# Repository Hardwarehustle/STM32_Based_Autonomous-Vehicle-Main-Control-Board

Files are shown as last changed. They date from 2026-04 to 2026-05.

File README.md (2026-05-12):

# Autonomous Vehicle — Main Control Board (OW_Main_PCB)

---

## Project Overview

This is the **main control board (MCB)** for an autonomous wheeled vehicle, designed to act as the central hub that interfaces the **STM32 Nucleo F446RE** with all vehicle subsystems — motor PWM outputs, relay-controlled actuators, RS-485 temperature sensing, W5500 Ethernet connectivity, and an RGB error-status LED. The board is designed in **KiCad EDA 9.0.7** on a rectangular PCB with four corner mounting holes for secure chassis mounting.

The MCB features:
- **STM32 Nucleo F446RE** piggyback mount on dual female header rows
- **W5500 Ethernet controller** for remote telemetry and control over TCP/IP
- **MAX485 RS-485 transceiver** for robust long-cable sensor/motor communication
- **2× OMRON G5LE-1 relays** for 12V actuator switching
- **4× PWM output ports** (Molex 4-pin) for motor speed control
- **2× Digital I/O ports** for external peripherals
- **RGB error indicator LED** with PWM dimming
- **Dual XT30 power inputs** (12V) with AMS1117-3.3 onboard LDO

---

## Project Visuals

### Schematic
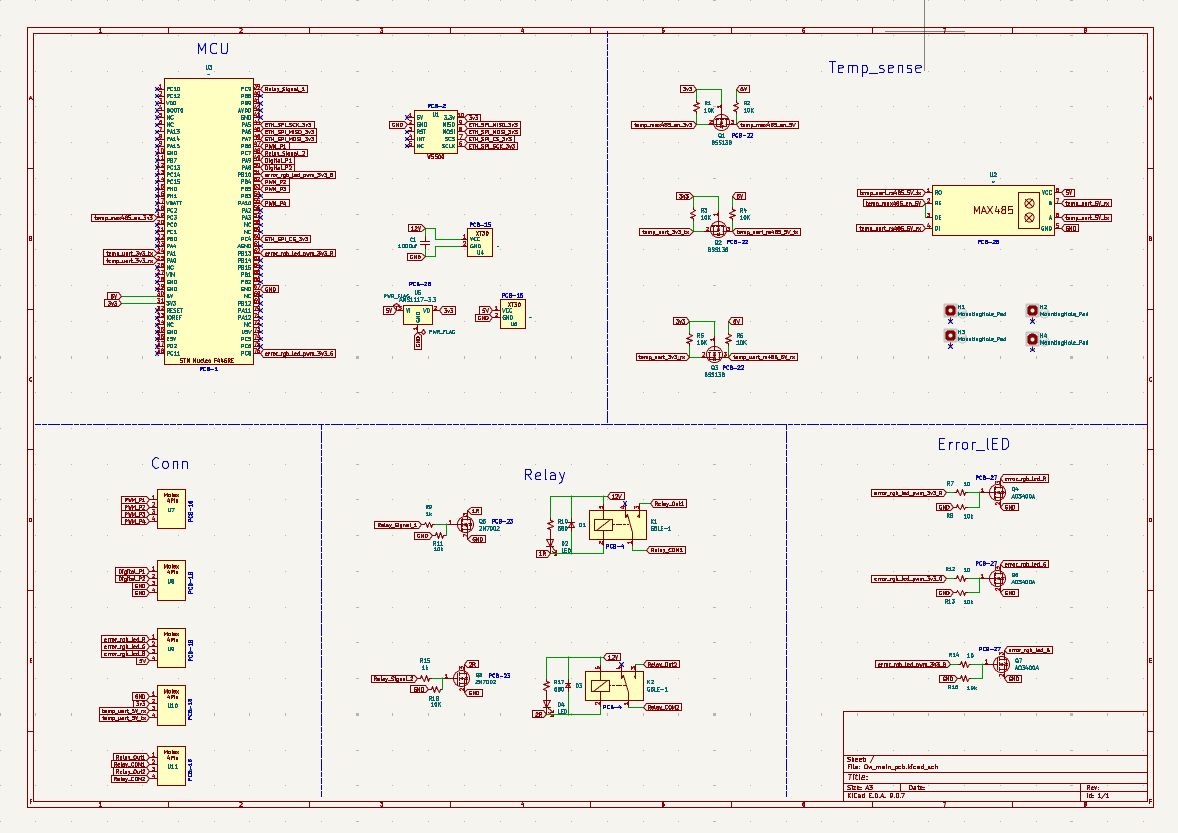
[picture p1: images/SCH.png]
Schematic


### PCB Layout
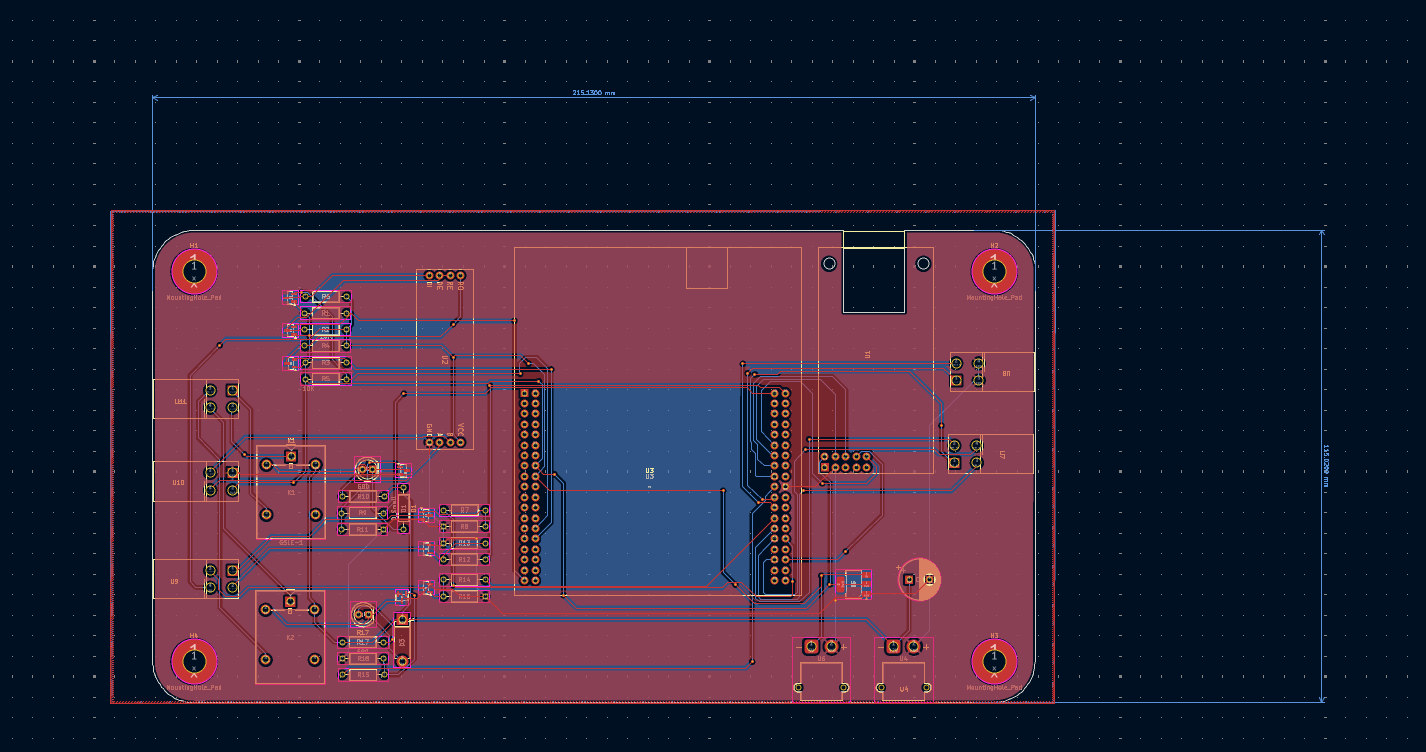
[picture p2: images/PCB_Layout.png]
PCB Layout


### 3D Board Top View
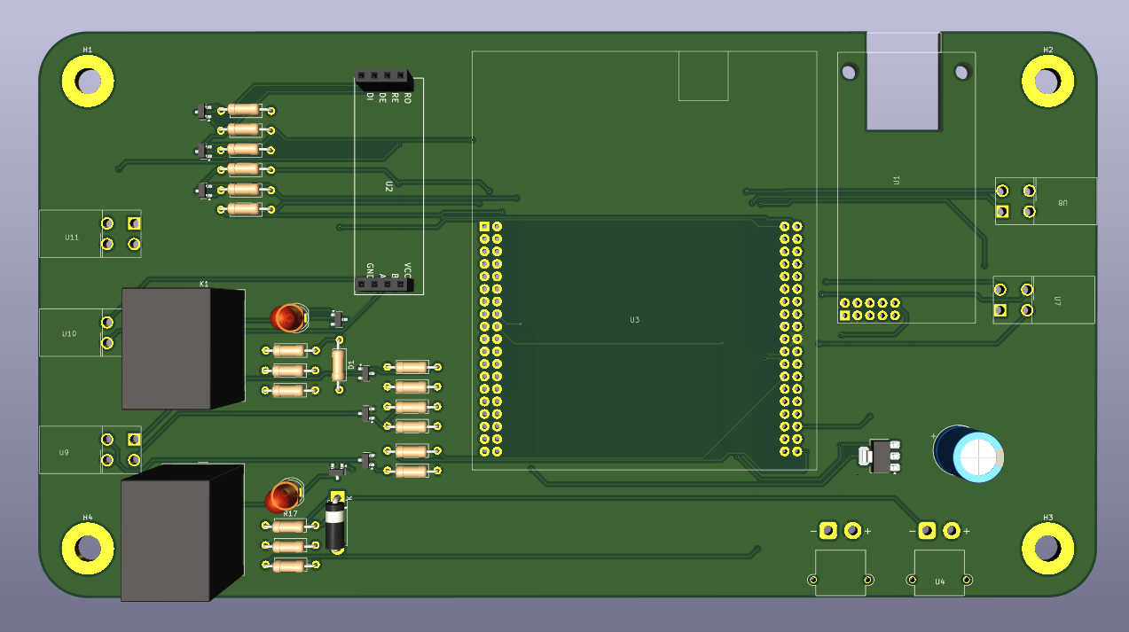
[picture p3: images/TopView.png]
3D Top View


### 3D Board Bottom View
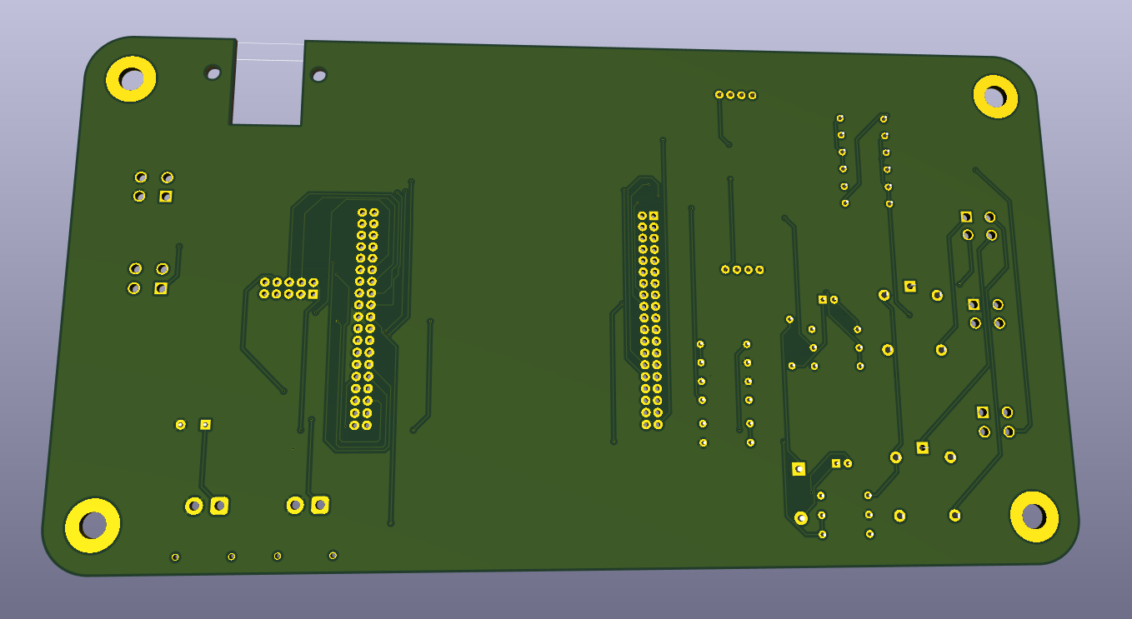
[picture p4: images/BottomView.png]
3D Bottom View


---

## System Architecture

```
12V Power (XT30 ×2)
      │
      ├──► Relay K1, K2 (12V switched outputs — G5LE-1)
      │
      └──► AMS1117-3.3 ──► 3.3V rail
              │
              ▼
      STM Nucleo F446RE (U3)  ◄──── USB/ST-LINK (onboard)
              │
   ┌──────────┼──────────────────────────────────┐
   ▼          ▼            ▼                    ▼
W5500       MAX485      4× PWM Ports      2× Relay Drivers
Ethernet    RS-485      (Motor Control)   (BSS138 / AO3400A)
(SPI 3.3V)  UART Bridge  PWM_P1–P4        K1, K2
   │                         │
   ▼                    Molex 4-pin
TCP/IP                   Connectors
Remote Ctrl              (U7–U11)
                              │
                    Temperature Sensor (RS-485 Bus)
                              │
                         Digital_P1, Digital_P2
                              │
                    RGB Error LED (R, G, B + PWM)
```

---

## Component BOM

### Core ICs & Modules

| Ref | Component | Part | Function |
|:---:|:---|:---|:---|
| U3 | MCU Board | STM Nucleo F446RE | Main controller (STM32F446RET6, 180 MHz) |
| U1 | Ethernet Controller | W5500 | SPI hardwired TCP/IP Ethernet |
| U2 | RS-485 Transceiver | MAX485 (DIP-8) | UART ↔ RS-485 bridge |
| K1, K2 | Relay | OMRON G5LE-1 | 10A SPDT 12V relay (×2) |
| U5 | LDO Regulator | AMS1117-3.3 | 5V → 3.3V supply |
| U6, U4 | Power Connector | XT30 | 12V input (×2) |

### MOSFETs

| Ref | Part | Type | Function |
|:---:|:---|:---|:---|
| Q1, Q2, Q3 | BSS138 | N-ch logic-level FET | Relay coil driving / signal switching |
| Q4, Q6, Q7 | AO3400A | N-ch 5.7A / 30V FET | High-current relay / actuator drive |
| Q5, Q8 | 2N7002 | N-ch logic-level FET | Level shifting / enable control |

### Passives & Indicators

| Ref | Value | Function |
|:---:|:---:|:---|
| R1–R6, R8, R11, R13, R16, R18 | 10 kΩ | Pull-up / pull-down resistors |
| R7, R12, R14 | 10 Ω | Current limiting / damping |
| R9, R15 | 1 kΩ | Gate / base resistors |
| R10, R17 | 680 Ω | LED current limiting |
| C1 | 1000 µF | Bulk supply decoupling |
| D2 | LED (Red) | Error RGB — Red channel |
| D4 | LED (Green) | Error RGB — Green channel |
| D3 | LED (Blue) | Error RGB — Blue channel |
| H1–H4 | MountingHole_Pad | PCB corner mounting holes |

### Peripheral Connectors

| Ref | Type | Signals | Function |
|:---:|:---:|:---|:---|
| U7 | Molex 4-pin | PWM_P1 | PWM Motor Port 1 |
| U8 | Molex 4-pin | PWM_P2 | PWM Motor Port 2 |
| U9 | Molex 4-pin | PWM_P3 | PWM Motor Port 3 |
| U10 | Molex 4-pin | PWM_P4 | PWM Motor Port 4 |
| U11 | Molex 4-pin | Digital_P1/P2 | Digital I/O Ports |

---

## Signal Net Map — STM32 Nucleo F446RE

| Net Name | Nucleo Pin | Function |
|:---|:---:|:---|
| ETH_SPI_MOSI_3v3 | PA7 | W5500 SPI MOSI |
| ETH_SPI_MISO_3v3 | PA6 | W5500 SPI MISO |
| ETH_SPI_SCK_3v3 | PA5 | W5500 SPI Clock |
| ETH_SPI_CS_3v3 | PA4 | W5500 SPI Chip Select |
| temp_uart_rs485_5V_tx | UART TX | MAX485 DI (RS-485 TX) |
| temp_uart_rs485_5V_rx | UART RX | MAX485 RO (RS-485 RX) |
| temp_max485_en_3v3 | GPIO | MAX485 RE/DE enable |
| PWM_P1 – PWM_P4 | TIM PWM pins | 4-channel motor speed control |
| Relay_Signal_1 | GPIO | Relay K1 coil trigger |
| Relay_Signal_2 | GPIO | Relay K2 coil trigger |
| error_rgb_led_pwm_3v3_R | TIM PWM | RGB LED Red (PWM) |
| error_rgb_led_pwm_3v3_G | TIM PWM | RGB LED Green (PWM) |
| error_rgb_led_pwm_3v3_B | TIM PWM | RGB LED Blue (PWM) |
| Digital_P1, Digital_P2 | GPIO | External digital peripherals |

---

## Subsystem Details

### Ethernet — W5500
The **W5500** is a hardwired TCP/IP Ethernet controller that offloads the full network stack (TCP, UDP, IPv4, ARP, ICMP) from the STM32. [web:79] It communicates via **SPI at up to 80 MHz** and supports **8 simultaneous sockets** with 32KB internal buffer. [web:81] This enables:
- Remote **telemetry streaming** (speed, sensor data, state)
- Remote **command injection** over TCP/UDP from a control PC or server
- **OTA firmware update** capability via Ethernet

### RS-485 — MAX485
The **MAX485** is a half-duplex RS-485/RS-422 transceiver driven by the STM32 UART. [file:71] It provides:
- **Up to 2.5 Mbps** data rate
- **±7V common-mode range** — robust against ground shifts in vehicle environments
- Communication with **temperature sensors** or **motor controllers** on a daisy-chain RS-485 bus
- RE/DE pin controlled by MCU GPIO (`temp_max485_en`) for TX/RX direction switching

### Relay Control — G5LE-1 (K1, K2)
Two **OMRON G5LE-1** relays switch 12V loads (actuators, lights, emergency stop) with a rated switching capacity of 10A at 250VAC / 30VDC. [file:71] Each relay is driven by an **AO3400A N-channel MOSFET** (Q4/Q6) with:
- 10kΩ gate pull-down for default OFF state
- BSS138 logic-level gate driver
- Flyback diode protection on coil

### PWM Motor Control
Four **Molex 4-pin ports (U7–U11)** expose PWM signals generated by the STM32's hardware timers. [file:71] Each port carries:
- PWM signal (motor speed reference)
- 5V / 12V power
- GND
- Optional digital I/O

### RGB Error LED
An **RGB LED (D2/D3/D4)** provides visual system status: [file:71]

| Color | State |
|:---:|:---|
|  Green | System OK / Running |
|  Yellow (R+G) | Standby / Initializing |
|  Red | Error / Fault detected |
|  Blue | Communication active |
|  White (all) | Bootup / Reset |

PWM versions (`error_rgb_led_pwm_3v3_R/G/B`) allow brightness control from 3.3V MCU GPIO.

---

## Power Architecture

```
12V Input (XT30 ×2)
   ├──► Relay K1, K2 (Relay_COM / Relay_Out — 12V switched)
   └──► 5V (from Nucleo E5V pin)
             └──► AMS1117-3.3 ──► 3.3V (W5500, MAX485, MOSFETs, LEDs)
```

| Rail | Source | Consumers |
|:---:|:---|:---|
| 12V | XT30 connector | Relays (K1, K2), Actuator outputs |
| 5V | Nucleo E5V / USB | MCU, Molex port power, MAX485 VCC |
| 3.3V | AMS1117-3.3 | W5500, MCU I/O, MAX485 logic, RGB LED |

---

## PCB Design Highlights

- **EDA Tool:** KiCad EDA 9.0.7
- **File:** `Ow_main_pcb.kicad_sch`
- **Board Shape:** Rectangular with 4× corner mounting holes (H1–H4) for chassis mount
- **MCU Mount:** STM Nucleo F446RE piggybacks via dual female 2.54mm pin header rows
- **W5500:** Module connector on right edge (SPI 3.3V + RST + INT)
- **Relays K1, K2:** Through-hole, positioned on left half for easy wiring to actuators
- **XT30 Power Inputs:** Dual XT30 connectors for redundant 12V supply or load balancing
- **Bulk Cap C1 = 1000µF:** Power supply stiffening for relay coil switching transients
- **MAX485 (DIP-8):** Socketed, top-left area, close to RS-485 screw terminals
- **RGB LED:** Bottom-right corner for clear visibility during operation

---

## Bring-Up & Testing Procedure

### Step 1 — Power Rail Verification
- Apply 12V via XT30 connector
- Measure: 3.3V at AMS1117 output, 5V at Nucleo 5V pin
- Idle current expected: ~120–200 mA (Nucleo + W5500 + logic)

### Step 2 — Nucleo Programming
- Connect USB to Nucleo ST-LINK port
- Flash STM32CubeIDE / PlatformIO project
- Verify UART output on `temp_uart_3v3_rx/tx`

### Step 3 — Ethernet Connectivity
- Connect RJ45 to W5500 module
- Ping the board IP from host PC
- Verify 8 socket handles, send/receive TCP packet

### Step 4 — RS-485 Communication
- Connect RS-485 sensor/device on MAX485 A/B terminals
- Send AT command / protocol frame from STM32 UART
- Verify loopback response and error-free receive

### Step 5 — Relay Test
- Set `Relay_Signal_1` GPIO HIGH
- Verify K1 coil energizes (click sound, ~12V on COM→OUT1)
- Test K2 same way; verify flyback diode absorbs coil spike

### Step 6 — PWM Motor Output
- Configure STM32 TIM for 20 kHz PWM on PWM_P1–P4
- Connect motor driver to Molex 4-pin connectors
- Sweep duty cycle 10%→90% — verify motor speed response

### Step 7 — Full System Integration
- Load autonomous vehicle firmware
- Verify telemetry stream over Ethernet to control station
- Test emergency stop via relay Relay_Signal_2
- Validate RGB LED state machine (Green = OK, Red = fault)

---

## Firmware Stack

```
STM32CubeIDE / PlatformIO (STM32F446RE target)
├── HAL_SPI         → W5500 Ethernet (ioLibrary_Driver / WIZnet HAL)
├── HAL_UART        → MAX485 RS-485 temperature bus
├── HAL_TIM_PWM     → 4× PWM motor ports (TIM1/TIM2/TIM3/TIM4)
├── HAL_GPIO        → Relay control, RGB LED, Digital ports
└── FreeRTOS        → Task scheduler (Sensing, Control, Telemetry)
```

---

## Repository Structure

```
AV-Main-Control-Board/
├── images/
│   ├── TopView.jpg                ← 3D board render
│   └── SCH.pdf                   ← KiCad schematic export
├── KiCad/
│   ├── Ow_main_pcb.kicad_sch     ← Schematic source
│   ├── Ow_main_pcb.kicad_pcb     ← PCB layout source
│   └── Ow_main_pcb.kicad_pro     ← Project file
├── Gerber/
│   └── (Gerber + drill files)
├── BOM/
│   └── BOM_AV_Main_PCB.csv
├── Firmware/
│   └── av_main_fw/
└── README.md
```

---

## Design Notes & Cautions

- **XT30 polarity** — always verify before powering; reverse polarity will damage AMS1117 and MCU
- **AO3400A gate drive** — logic-level FET, fully enhanced at 3.3V (Vgs(th) = 0.45–1.0V typ.)
- **W5500 is 3.3V only** — do not connect 5V to any W5500 pin; level-shift if feeding from 5V MCU GPIO
- **MAX485 RE/DE** — ensure MCU drives `temp_max485_en` LOW before entering receive mode to avoid bus contention
- **G5LE-1 coil voltage = 12V** — ensure relay drive MOSFETs (AO3400A) pull coil to GND; 12V is supplied via XT30
- **C1 = 1000µF** must be low-ESR type (electrolytic or tantalum) to handle relay switching transients cleanly

---

## License

This project is open for educational and personal use.  
© 2025 Janardhan BV — All rights reserved.

---

## Author

**Janardhan BV**  
Embedded Hardware Engineer | PCB Design
Bengaluru, India

---
*Designed in KiCad EDA 9.0.7 | STM32 Nucleo F446RE — Autonomous Vehicle Main Control Board*

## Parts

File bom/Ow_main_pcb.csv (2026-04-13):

Id | Designator | Footprint | Quantity | Designation | Supplier and ref
1 | Q8,Q5 | SOT-23 | 2 | 2N7002
2 | R7,R12,R14 | R_Axial_DIN0207_L6.3mm_D2.5mm_P10.16mm_Horizontal | 3 | 10
3 | U7,U11,U9,U10,U8 | Molex_2x2_4.2mm | 5 | ~
4 | R1,R18,R6,R2,R4,R5,R3 | R_Axial_DIN0207_L6.3mm_D2.5mm_P10.16mm_Horizontal | 7 | 10K
5 | D4,D2 | LED_D5.0mm | 2 | LED
6 | D1 | R_Axial_DIN0207_L6.3mm_D2.5mm_P10.16mm_Horizontal | 1 | D_Small
7 | R8,R16,R13,R11 | R_Axial_DIN0207_L6.3mm_D2.5mm_P10.16mm_Horizontal | 4 | 10k
8 | Q2,Q3,Q1 | SOT-23 | 3 | BSS138
9 | R9,R15 | R_Axial_DIN0207_L6.3mm_D2.5mm_P10.16mm_Horizontal | 2 | 1k
10 | Q6,Q7,Q4 | SOT-23 | 3 | AO3400A
11 | U3 | Nucleo_F446RE | 1 | ~
12 | D3 | D_5W_P10.16mm_Horizontal | 1 | D_Small
13 | U1 | W5500 | 1 | ~
14 | U5 | SOT-223-3_TabPin2 | 1 | AMS1117-3.3
15 | R10,R17 | R_Axial_DIN0207_L6.3mm_D2.5mm_P10.16mm_Horizontal | 2 | 680
16 | U2 | MAX485_Module | 1 | ~
17 | K2,K1 | Relay_SPDT_Omron-G5LE-1 | 2 | G5LE-1
18 | C1 | CP_Radial_D10.0mm_P5.00mm | 1 | 1000uf
19 | U4,U6 | AMASS_XT30PW-M_1x02_P2.50mm_Horizontal | 2 | ~

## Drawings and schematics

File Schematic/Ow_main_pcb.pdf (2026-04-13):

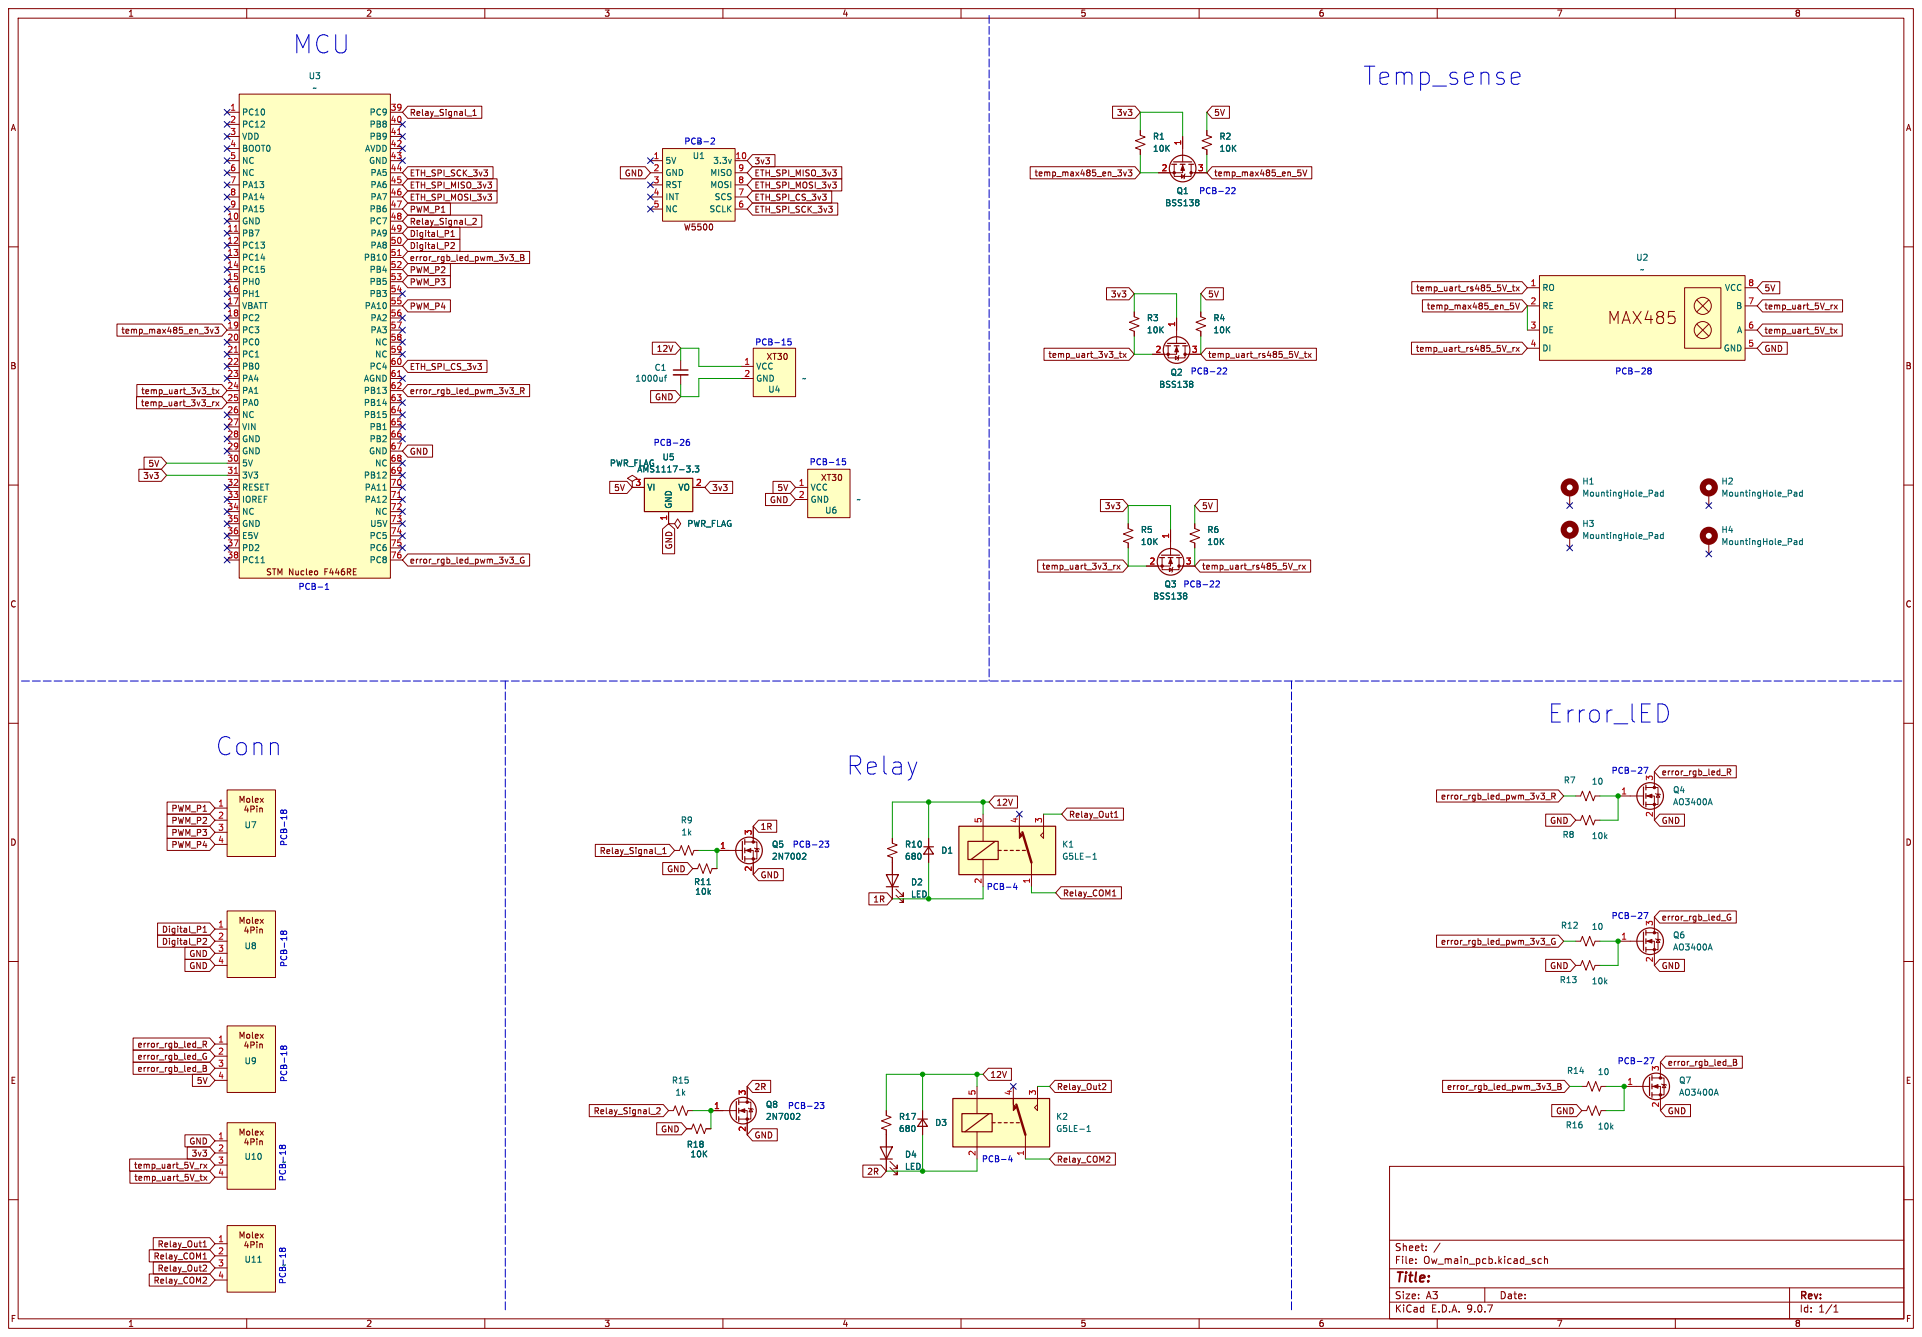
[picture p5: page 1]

PCB-15 MCU
3.3v 10 MISO 9 MOSI 8 SCS 7 SCLK 6 U1~ PWR_FLAG
3v3 ETH_SPI_SCK_3v3 ETH_SPI_MOSI_3v3 GND

PCB-22 PCB-18 PCB-18 PCB-18 PCB-18

Id: 1/1 Title: File: Ow_main_pcb.kicad_sch Sheet: /

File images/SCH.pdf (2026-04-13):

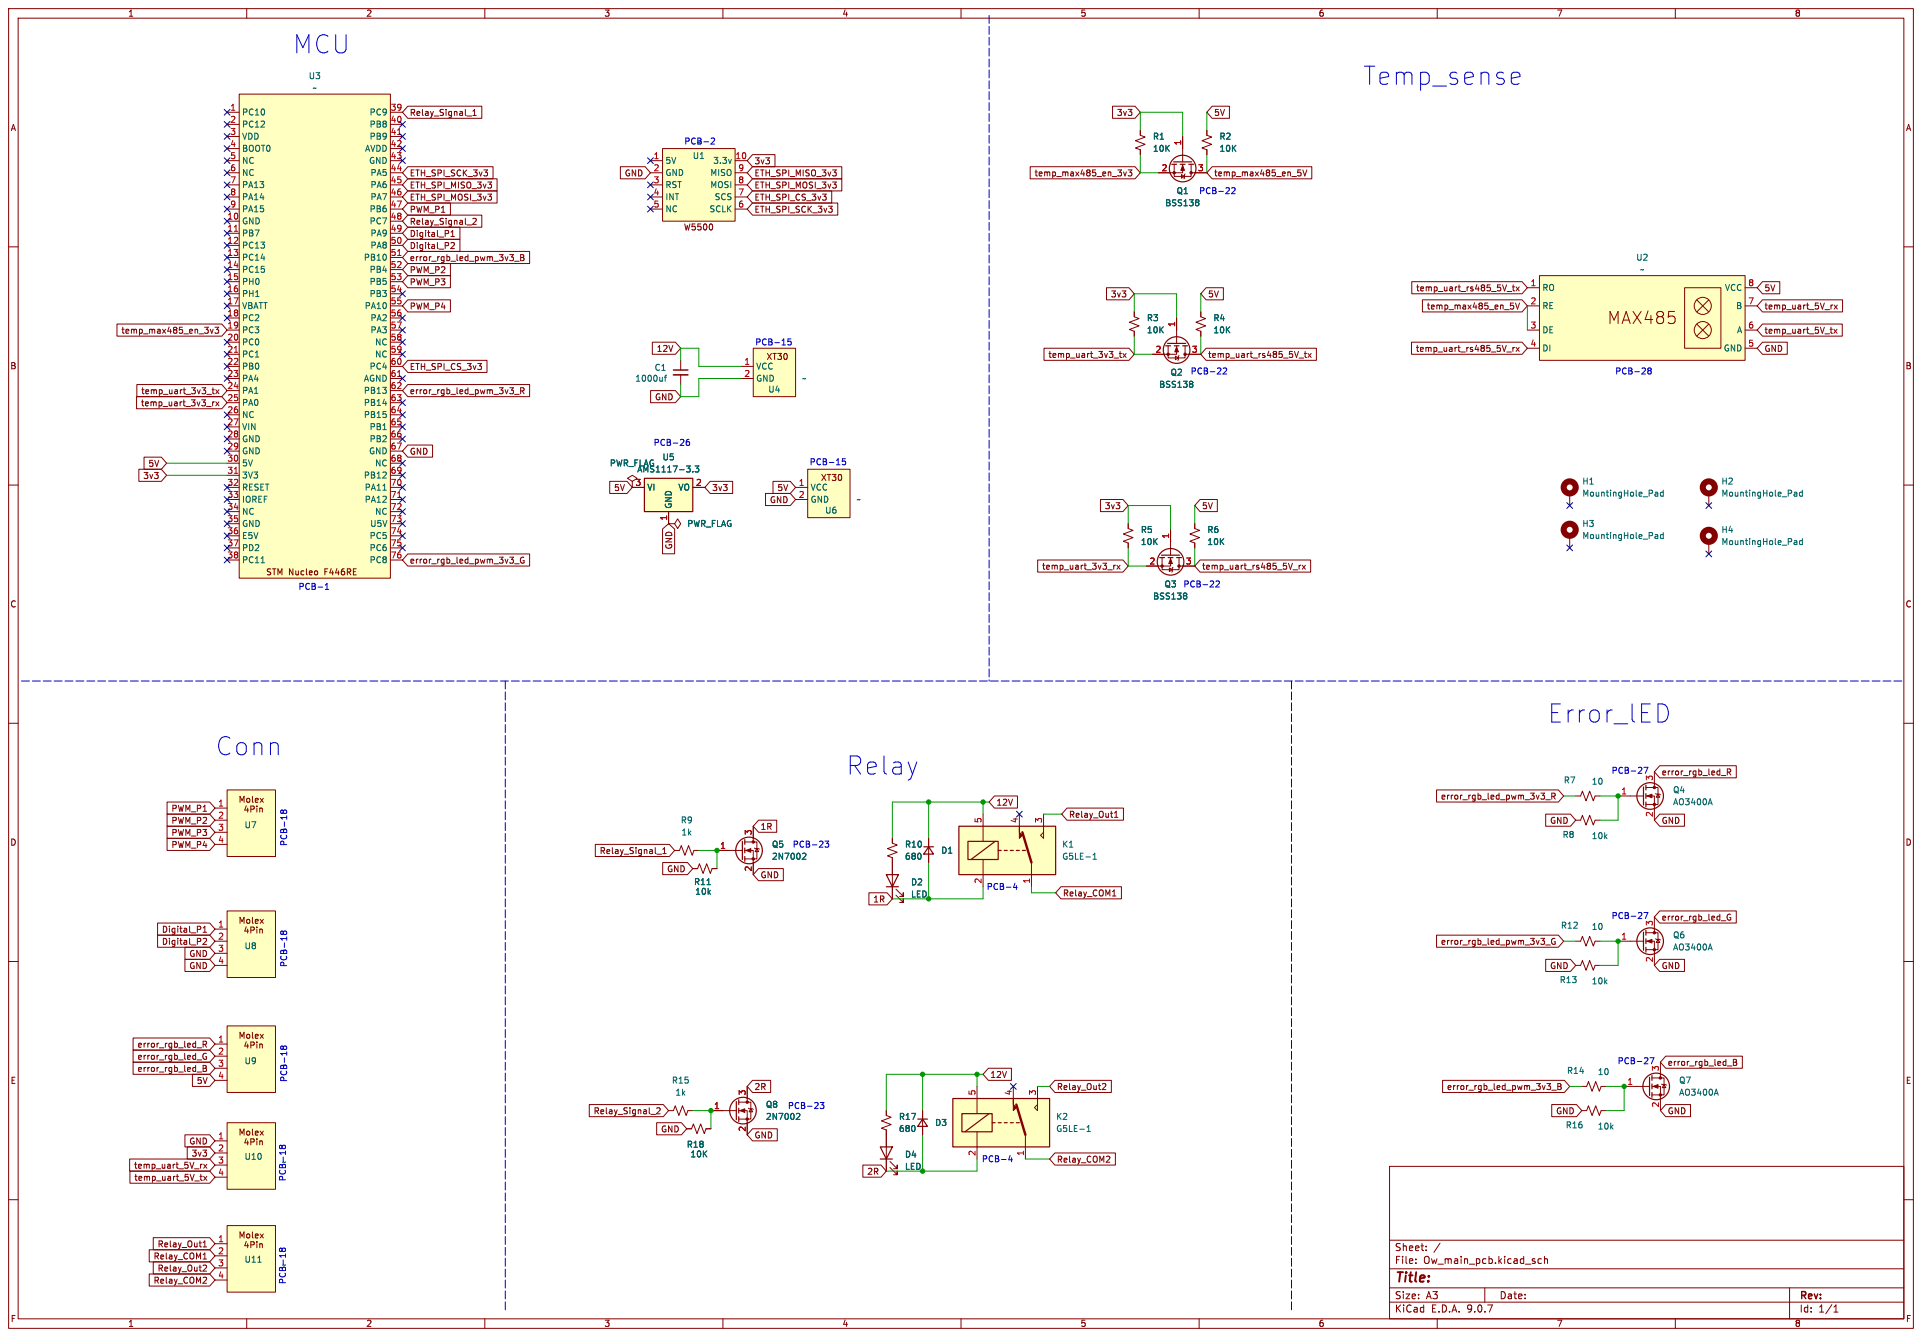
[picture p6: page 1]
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

Id: 1/1 Title: File: Ow_main_pcb.kicad_sch Sheet: /

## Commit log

2026-04-13 Revise README for Autonomous Vehicle Main Control Board
    Updated project details, overview, and components for the autonomous vehicle main control board.
2026-05-12 Update author description in README
    Removed 'Power Electronics' from author description.
